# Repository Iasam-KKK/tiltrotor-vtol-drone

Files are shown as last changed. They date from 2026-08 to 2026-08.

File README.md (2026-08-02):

# Tri-Tiltrotor VTOL — PX4 + Gazebo Harmonic

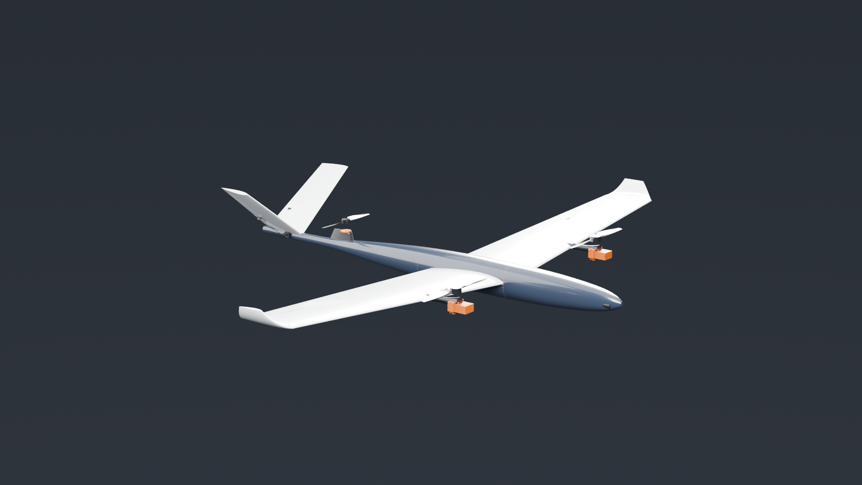
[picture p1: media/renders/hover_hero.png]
Tri-tiltrotor in the hover configuration, both wing rotors tilted thrust-up


A **three-rotor tilt-rotor VTOL** for PX4 SITL, built to the layout production
aircraft in this class actually use: two tilting rotors on the wing ahead of the
CG, and one **fixed, hover-only lift rotor** on a pylon at a waisted fuselage
station, ahead of a V-tail.

PX4 ships a **quad** tiltrotor (four motors, two of them tilting). This is a
**tri** — one fewer motor, ESC and propeller — and upstream provides no model
for it.

**Why the lift rotor is fixed, not tilting.** A tilting tail rotor keeps
producing thrust in cruise, but it also lays a wake over whatever sits behind
it. A hover-only rotor is stopped in cruise, so the V-tail behind it flies in
clean air in the only regime where tail effectiveness matters for stability.
The fuselage narrows **57%** ahead of the pylon so the rotor draws air already
squeezed clear of most of the boundary layer. The cost is a stopped disc in
cruise — about 1 N against a 3.3 N requirement — which is why the BOM specifies
a **folding** propeller, and why `check()` refuses a fixed rotor without one.

```bash
git clone <this repo> && cd 04-tiltrotor-vtol
bash sim/install_into_px4.sh ~/PX4-Autopilot   # symlink airframe + model
cd ~/PX4-Autopilot && make px4_sitl gz_tri_tiltrotor
# then at the pxh> prompt:
#   commander takeoff
#   commander transition
```

| Hover — rotors up | Cruise — rotors forward |
|---|---|
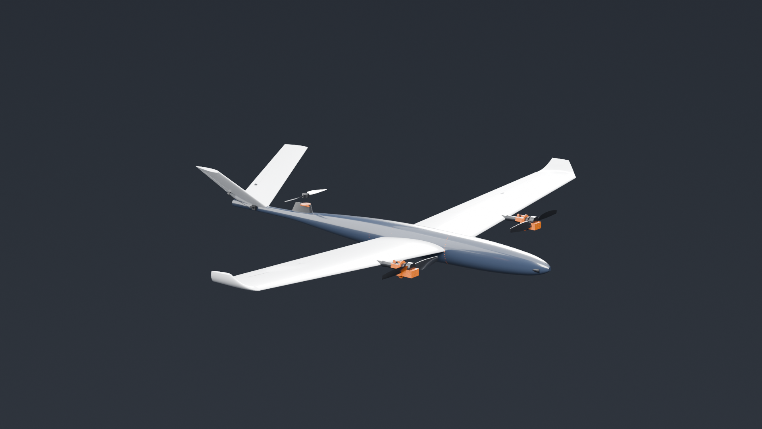
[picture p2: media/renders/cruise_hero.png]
cruise
| hover |  |

Both rendered from the **same CAD**, at the two ends of the tilt range. Nothing
was moved by hand: `render/assembly.json` is generated from `cad/params.py`, so
the pictures and the simulator are driven by one set of numbers. The camera is
generated too — it solves its own distance by projecting the aircraft's
bounding box onto the image plane, because a hardcoded camera position is a
latent bug in a parametric project: change the span and a wingtip leaves the
frame silently.

```bash
powershell -File render/render_all.ps1     # 12 renders, ~6 s each on GPU
```

---

## Verified, with numbers

Nothing below is asserted. Each row is produced by a script in `sim/` that you
can re-run.

| Claim | Measurement | How |
|---|---|---|
| Design closes | **118/118** invariants | `cad/params.py` |
| Model is valid | **13/13** | `sim/validate_model.sh` |
| CAD is manufacturable | STEP round-trip **0.000000 mm³** | `cad/gen_nacelle.py` |
| **It hovers** | climbed to **10.071 m** vs 10.0 m commanded | `sim/verify_hover.sh` |
| **It transitions** | both tilting nacelles **0.5° → 89.5°** | `sim/verify_transition.sh` |
| Control surfaces fit the wing | cutter **100.0%** inside the wing solid | `cad/probe_ctrl_fit.py` |
| Every avionics box fits its station | 7 items vs the lofted section | `cad/params.py` |
| ~~It glides~~ | **NOT VERIFIED — see below** | `sim/verify_glide.sh` |

The hover and transition rows were re-measured after the pitch and geometry
corrections: hover reached **10.068 m** against 10.0 m commanded (5/5), and
both tilting nacelles ran **0.0° → 89.6° / 89.5°** with 3/3 rotors turning.

### The glide test does not currently test anything

`sim/verify_glide.sh` was the only script here that tests the **aerodynamic**
model rather than a mechanism, and it is the one that does not work. It is
listed as unverified above rather than quietly dropped.

It commands the descent the polar predicts as an offboard **NED velocity**
setpoint, then measures travel over height lost. Run unattended end to end
(`sim/verify_glide_auto.sh`), the aircraft flies at **35.5 m/s** against a
commanded 14.76, sinking **0.164 m/s** against a predicted 0.941 — an implied
glide ratio of **217** for an airframe whose derived (L/D)max is ~15.

The cause is not the drag model. **PX4 does not act on offboard NED velocity
setpoints in fixed-wing mode**; the setpoint is accepted and ignored, and the
fixed-wing controller holds altitude at its own airspeed. The measurement was
never of a glide. Two things kept this hidden:

- The script's only sanity check was "did it descend at all". Powered
  near-level flight descends slightly, and dividing by a near-zero sink rate
  produces a magnificent glide ratio. There is now a **speed gate**: if ground
  speed exceeds 1.35 × the commanded best-glide speed, it reports powered
  flight instead of a number.
- The line that prints the comparison had a shell-quoting bug that crashed it
  (`g['v_best_glide_ms']` inside a single-quoted shell block ends the string).
  It had never once run, because every previous attempt exited earlier at the
  "not descending" branch. **A test that has never reached its assertion is
  not a passing test.**

The honest position: the drag polar is derived and traceable, and it is
**untested**. Testing it needs a throttle-cut path — commanding zero thrust
directly, or a fixed-wing descent PX4 will actually fly — not a velocity
setpoint.

Nacelle angle through the manoeuvre, read from Gazebo's joint state rather than
from a log line (0° = thrust up, 90° = thrust forward):

```
tilt_left    37.1   0.5   3.1   1.4   3.5   3.7  38.0  89.5  89.5  89.5
tilt_right   37.1   0.5   7.6   5.8   7.9   8.0  41.5  89.6  89.6  89.6
             spawn  ├──── hover ────┤ ├rotating┤ ├─── cruise ───┤
```

The fixed lift rotor is emitted as a `fixed` joint, so it correctly never
appears in this data — and all 3 rotors are confirmed spinning.

⚠️ These numbers were re-measured after the airframe changed.

---

## The aircraft

| | |
|---|---|
| MTOW / span / wing area | 4.64 kg · 2.00 m · 0.520 m² |
| Wing loading · aspect ratio | 8.92 kg/m² · 7.69 (**8.31 effective**, winglets) |
| Airfoil | NACA 2410, taper 0.65, 4° dihedral, −2° washout, winglets |
| Rotor stations from CG | wing **+0.173 m** (tilting), lift rotor **−0.700 m** (fixed) |
| Tail | V-tail at **−0.870 m**, 36.4° dihedral, 0.128 m² |
| Hover trim (solved) | wing 17.79 N each, lift rotor 9.92 N (**21.8%** of lift) |
| Fuselage | 1.55 m, fineness **12.7**, waisted 70% at the pylon |
| Stall → transition → cruise | 11.51 → 14.96 → 19.0 m/s  (measured section) |
| Cruise L/D · best L/D | **13.05** at 19 m/s · **15.04** at 14.46 m/s |
| Unpowered glide | **3.81°**, sink **0.960 m/s** |
| Servos · peak servo current | 4 surface + 2 tilt · **15 A** (needs its own BEC) |
| Payload | 1080p nose camera, 45 g, 78° HFOV, 15° down |

### Why the rotors straddle the CG

A layout with both tilt rotors *behind* the CG cannot be trimmed in hover: total
lift acts aft of the centre of mass and produces an unopposed nose-down moment
of W·L that no combination of thrust and tilt can cancel. Putting rotors on both
sides of the CG is what makes hover pitch controllable, and it is enforced as an
invariant (`rotors straddle the CG`) rather than left to inspection.

### Yaw is single-path, deliberately

The wing pair carries yaw by differential tilt (ArduPilot calls the equivalent
`Q_TILT_TYPE=2`), travelling 15° aft of vertical. The tail nacelle **cannot**
contribute yaw — a centreline force in the x–z plane produces no moment about z
— so it carries pitch instead (`CA_SV_TL2_CT=2`). Yaw authority is 4.96 rad/s²
from wing vectoring alone.

---

## One source of truth

Every dimension lives in [`cad/params.py`](cad/params.py) and nowhere else.
The Gazebo model, the PX4 airframe, the lofted geometry and the printed nacelle
are all *generated* from it, so they cannot drift apart.

```
cad/params.py ──┬─→ gen_sdf.py           → sim/models/tri_tiltrotor/model.sdf
                ├─→ gen_airframe.py      → sim/airframes/4030_gz_tri_tiltrotor
                ├─→ gen_geometry.py      → lofted wing / fuselage / tail /
                │                          control surfaces / booms / props
                ├─→ gen_nacelle.py       → printable cradle, yoke, fit coupon
                ├─→ gen_manifest.py      → render/assembly.json  (Blender)
                ├─→ gen_flight_params.py → sim/ros2/flight_params.json  (ROS 2)
                ├─→ gen_layout.py        → docs/equipment-bay.svg
                ├─→ gen_bom.py           → docs/BOM.csv
                ├─→ gen_cfd_surface.py   → cfd/geometry/  (wetted OML only)
                └─→ gen_cfd_case.py      → cfd/case/      (OpenFOAM)
```

`gen_flight_params.py` exists because the ROS 2 teleop node runs under WSL's
system Python and cannot import `params.py` (Windows-side 3.12 venv with
build123d). Without it the glide speed would have to be retyped into the node
and would drift the moment the polar changed.

## Running it

See [`RUN.md`](RUN.md) — three commands, plus the environment traps that make
the difference between "it works" and "it silently does nothing".

`params.check()` runs 118 invariants in arithmetic *before* any CAD kernel or
simulator starts, and refuses to emit an aircraft that cannot fly. It has
already caught, on real runs:

- a mass budget short by **0.88 kg** (battery folded into "fuselage")
- a horizontal tail sitting **inside the tail rotor's disc**, which would have
  flown in its own wash
- its own bad arithmetic — a bolt-pattern check that double-counted and failed
  a design that was fine

### Six defects this structure caught, and one it didn't

Every one of these passed the invariant suite as it stood. They are listed with
what was wrong, how it was actually found, and what now prevents a repeat —
because "we have 118 checks" is worth nothing next to what the checks missed.

| Defect | Found by | Why the checks missed it |
|---|---|---|
| **Aerofoil built upside down.** `Plane(x_dir=(1,0,0), z_dir=(0,1,0))` has in-plane Y = `(0,0,-1)`, so NACA 2410's camber pointed at the ground on the wing, winglets, tail and propeller blades. | Extruding one root section in isolation: sketch Y `-21.5..+10.2` → model z `-10.2..+21.5` | Nothing inspected the mesh. `LiftDrag` reads coefficients and joint angles, never geometry, so it flew correctly while looking wrong. A first probe read the wing **bounding box** and concluded the opposite — the winglet at +152 mm dominates it. |
| **Wing boom slung under the wing.** Centred 14 mm below the chord line, spanning −22.0…−6.0 mm against a skin at −8.3…+18.4 mm: 13.7 mm proud, applying nacelle load on a lever arm instead of in shear. | Measuring the section at the boom station | The boom's `z` was a literal in `gen_geometry.py` that `params.py` never saw. Now asserted **where the number lives**, not in `check()`. |
| **Control surfaces overlapping the wing.** Built as separate solids while the wing kept its full chord — two solids in one space. | Volume arithmetic: the wing lost 57.5 cm³ to a 478 cm³ cutter | No check compared the surfaces to the wing. Now the surface *is* the wing's own aft portion (`wing ∩ prism`), 100% by construction. |
| **V-tail bolted to nothing.** The body ended at −0.872 m; the tail root chord runs to −1.005 m. 133 mm of a 180 mm root cantilevered into open air. | Reading the station table against the tail chord | The invariant was called *"fuselage is long enough to carry the tail"* and compared **two lengths** (1.35 vs 0.956 m). It never asked where anything was. |
| **Takeoff nose-up.** `CA_ROTOR*_CT` defaults to 6.5 for every rotor; ours are 38 N and 25 N. PX4 asked the tail for 9.32 N and got ~66%, leaving ~2.2 N·m of unopposed nose-up at 0.700 m aft. | PX4's own `module.yaml`: *"Thrust = CT · u²"* | Stock `4020_gz_tiltrotor` omits `CT` too — correctly, because its four rotors are identical and the error is common-mode. Ours are not. |
| **CG 11.2 mm off.** `base_link`'s inertial sat at the origin while five links hung mass elsewhere; every `CA_ROTOR*_PX` is quoted from the CG. | Summing m·x across the emitted SDF | `params.check()` verified the *design* CG arithmetic. Nothing verified that the *generated SDF* put mass where the design said. |
| **BOM had no control-surface servos.** Listed 3 tilt servos, zero aileron or ruddervator servos, while PX4 has allocated four (`CA_SV_CS0..3`) since the V-tail was adopted. | Reading the BOM against the airframe | Nothing cross-checked the parts list against the control allocation. An aircraft built to that list would have had no roll, pitch or yaw in forward flight. |

The pattern worth taking away: **five of the seven were checks whose *name*
claimed a guarantee their *arithmetic* could not deliver.** A check with a
constant on both sides (`3 <= 4`) cannot fail, and cannot help.

### What AVL found, and what it fixed

`cad/gen_avl.py` emits a vortex-lattice model from the same `params.py`;
`aero/run_avl.sh` trims it at the cruise CL. It immediately found two defects,
both now fixed.

**1. The MAC was located as if the wing were rectangular.** The wing is placed
by its **root** quarter-chord, but the aircraft balances about the **mean
aerodynamic** chord — and on a wing with 3° of leading-edge sweep those are not
the same station. The MAC quarter-chord sits **24.4 mm aft** of the root's.
Every call site computed `CG_MAC_FRACTION * WING_CHORD - 0.25 * WING_CHORD`
inline, in **eight separate files**, and all eight placed the root where the MAC
belonged. The whole wing sat 24.4 mm too far aft.

The result: `params.py` printed *"CG at 28% MAC"* while the aircraft actually
had its CG at **18.6% MAC**. The error was invisible because it is in the safe
direction — more nose-heavy, more stable — and because the expression was
duplicated rather than written once.

The fix names the distinction that caused it: `mac_quarter_chord_x()` and
`wing_root_quarter_chord_x()` are now two functions in `params.py`, and nothing
computes either inline. Measured after the fix: **CG at 28.00% MAC.**

**2. The V-tail had no incidence, so the elevator carried the trim.** The
ruddervators sat 8.67° from neutral in cruise, permanently. `params.py` had no
tail incidence parameter at all. `aero/solve_tail_incidence.sh` runs AVL at two
incidences and interpolates to zero elevator — the relationship is linear, so
two runs give it exactly. Answer: **−2.49°**, leading edge down.

| trimmed at cruise CL 0.403 | before | after |
|---|---|---|
| **Static margin** | 28.3% MAC | **19.5%** |
| **Trim elevator** | **−8.67°** | **+0.015°** |
| Induced drag CDind | 0.0068252 | **0.0063360** (−7.2%) |
| Span efficiency (Trefftz) | 1.144 | **1.236** |
| Cm_α | −1.474 | −1.018 |
| Cn_β (yaw stiffness) | 0.0658 | 0.0644 — kept |
| Cmq (pitch damping) | −12.77 | −12.29 — kept |
| Spiral `Clb·Cnr/Clr·Cnb` | 1.065 | **1.127** |

Both axes of authority survived intact, which was the point of fixing the CG
rather than shrinking the tail.

### Why the tail was not resized

The obvious response to 28% static margin is a smaller tail. AVL says no.
Sweeping tail area (`aero/sweep_tail.sh`):

| tail area | SM % | Cmq | Cn_β |
|---|---|---|---|
| 1.00 | 28.3 | −12.77 | 0.0658 |
| 0.70 | 22.1 | −9.11 | 0.0458 |
| 0.50 | 17.9 | −6.73 | 0.0324 |

**Halving the tail buys 10 points of static margin and costs 47% of the pitch
damping and 51% of the yaw stiffness** — and 0.0324 is below the ~0.05 usually
wanted for directional stability. Cmq scales with area × arm², so it falls
faster than the static margin improves; a tail *volume coefficient* cannot see
that, which is exactly the trap the sizing literature warns about.

It also fights itself: removing ~66 g of tail structure 0.870 m aft moves the
CG **12.6 mm forward**, giving back nearly half the margin just bought. And a
V-tail carries pitch and yaw on the *same* surfaces, so shrinking costs both at
once — there is no trade available.

Fixing the CG achieved more, for free.

### Aerodynamics are measured, not guessed

The section coefficients were hand-estimated, then derived from thin-airfoil
theory, and are now **measured** — XFOIL run on NACA 2410 at this aircraft's own
Reynolds numbers (`aero/run_xfoil.sh`, Ncrit 5, because the wing is printed).

| 2-D section | Guessed | Theory | **XFOIL, measured** |
|---|---|---|---|
| CL_α | 5.20 /rad | 6.283 (2π) | **6.022** |
| CL_max | 1.20 | 1.40 | **1.219** |
| CD_min | 0.028 | 0.0069 | **0.00868** |
| Stall α | 15° asserted | 15.5° | **13.18°** |

The measurement is taken at the **converged stall Reynolds number of 199,489**,
which is a fixed point: CL_max sets the stall speed, the stall speed sets the
chord Reynolds number, and that sets CL_max.

**Theory was wrong in the direction that flatters the aircraft, and worst where
it matters.** CL_max was 15% optimistic at exactly the low Reynolds number where
stall happens, and CD_min of 0.0069 turned out to be roughly the *Re 1,000,000*
figure for a wing that never exceeds 393,000. What that cost:

| | before | after |
|---|---|---|
| Stall speed | 10.74 m/s | **11.51 m/s** (+7.2%) |
| Transition speed | 13.96 | 14.96 m/s |
| CD0 (whole aircraft) | 0.02132 | 0.02310 |
| (L/D)max | 15.65 | **15.04** (−3.9%) |

All **118 invariants still pass** — the aircraft still closes, the envelope just
sits 7% higher. One consequence is now decisive rather than marginal: the
minimum-power speed (max endurance for a propeller aircraft) works out at
**0.955 × stall**, i.e. below stall. It is not a speed this aircraft can fly.
Loiter at 1.2 × stall = **13.81 m/s**.

---

## Against what PX4 ships

| | stock `gz_tiltrotor` | this |
|---|---|---|
| Configuration | quad, 2 of 4 tilt | **tri**, 2 tilting + 1 fixed lift |
| Motors / ESCs / props | 4 | **3** |
| Fuselage | one box, 0.55 × 2.144 × 0.05 m | lofted through 15 stations, **waisted** at the pylon |
| Main wing lift surface | **none** — elevons stand in for the wing | per-panel, at computed centres of pressure |
| Wing | rectangular plank | NACA 2410, tapered, dihedral, washout, **winglets** |
| Tail | separate stabiliser + fin | **V-tail**, dihedral derived from required effectiveness |
| Rudder | ±0.01 rad, LiftDrag **commented out** | functional, both ruddervators live |
| Airspeed sensor | absent | present (required to gate transition) |
| Aero coefficients | hand-entered | **derived from the section** |
| Verification | none | 4 scripts, 74 assertions |

---

## Repository layout

```
cad/     params.py + four generators, STEP output
sim/     model, airframe, worlds, and the verification scripts
media/   video masters (generated; see sim/capture_video.sh)
docs/    build notes and the environment gotchas
```

### Scripts

| Script | Does |
|---|---|
| `sim/install_into_px4.sh` | symlinks airframe + model into a PX4 checkout, idempotent |
| `sim/validate_model.sh` | SDFormat validity, structure, headless load |
| `sim/verify_hover.sh` | commands takeoff, measures altitude from Gazebo's pose topic |
| `sim/verify_transition.sh` | reads actual tilt joint angles through the manoeuvre |
| `sim/verify_glide_auto.sh` | PX4 + agent + scripted flight + glide measurement, unattended |
| `sim/capture_video.sh` | headless flight recording, Gazebo → ROS 2 → MP4 |
| `sim/run_gui.sh` | interactive run with the Gazebo GUI |

---

## Pinned versions

Reproducibility is the point; these are the versions it was verified against.

| | |
|---|---|
| PX4-Autopilot | **v1.17.0** |
| Gazebo | **Harmonic, gz-sim 8.11.0** |
| ROS 2 | **Jazzy** (used for the video bridge) |
| Ubuntu | **24.04 noble** (WSL2) |
| build123d | **0.11.1** on Python 3.12 |
| Airframe ID | **4030** `gz_tri_tiltrotor` |

---

## Honest limitations

- **Simulation only.** No physical aircraft exists. Nothing here has been flown
  or wind-tunnel tested, and the nacelle tolerances are verified in CAD only.
- **Aerodynamic coefficients are derived from thin-airfoil theory and published
  section data**, not from CFD or measurement. They are traceable, not exact.
- **Inertia is estimated** from a rod-and-point-mass model, good to perhaps
  ±25%. The control-authority margins are wide enough that this does not change
  any conclusion, but it is an estimate.
- **The transition is verified as "the nacelles rotate through 90° in flight".**
- **The drag polar is untested.** See the glide section above. It is derived
  from the section and the planform and nothing has yet measured it.
- **No endurance figure exists.** Battery mass is an input to `params.py`, not
  a result: there is no power-required calculation and no flight-time estimate,
  so the aircraft cannot currently answer the first question any buyer asks.
- **No constraint analysis.** Wing loading (8.92 kg/m², 1.83 lb/ft²) and
  installed thrust were chosen, not derived from intersecting hover, climb,
  transition and cruise constraints.
- **Stability is now computed, and it found two things** — see below.

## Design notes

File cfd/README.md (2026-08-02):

# CFD — measuring the drag polar

`params.py` **derives** a drag polar from thin-airfoil theory and the planform.
Nothing has ever **measured** it. `sim/verify_glide.sh`, which was supposed to,
does not work (see the project README). This directory is the attempt to close
that gap.

```bash
bash cfd/install_openfoam.sh          # once; then open a NEW shell
.venv-cad/Scripts/python.exe cad/gen_cfd_surface.py
.venv-cad/Scripts/python.exe cad/gen_cfd_case.py --alpha 0
bash cfd/run_case.sh                  # ~30-90 min
bash cfd/sweep_alpha.sh 0 2 4 6 8     # overnight; produces polar.csv
```

Everything under `case/` and `geometry/` is **generated** and git-ignored. The
two generators in `cad/` are the source, so the CFD geometry cannot drift away
from the flying model or the printed parts.

## Read this before believing a number

**The Reynolds number is the problem.** 329,000 at cruise, 223,000 at loiter,
186,000 at stall, all on the MAC. That is low-Re transitional flow. The real
boundary layer runs laminar over a meaningful fraction of the chord and often
separates into a bubble before reattaching turbulent.

A fully-turbulent k-ω SST run assumes turbulence from the leading edge and will
**overpredict skin-friction drag**, sometimes by tens of percent at this scale.
The case therefore defaults to **k-kL-ω**, which is transition-sensitive. That
is an improvement, not a solution: transition models at Re 2×10⁵ are themselves
sensitive to the inlet turbulence intensity, which here is a guess (0.1%).

So: **CFD is a bracket, not an oracle.** Thin-airfoil theory underpredicts CD0;
fully-turbulent RANS overpredicts it. Expect the truth between them, and say so
in any listing rather than quoting a CFD number as measurement.

**Cheaper tools answer most of this faster.** XFOIL gives 2-D section polars at
the exact Reynolds number in seconds, and AVL gives span loading, induced drag
and the stability derivatives this project still lacks, in minutes. Run those
first. CFD earns its cost on things they cannot do: fuselage interference, the
waisted pylon, nacelle drag, and prop-wing interaction.

## What the case is

| | |
|---|---|
| Solver | `simpleFoam`, steady incompressible RANS |
| Turbulence | `kkLOmega` (default) or `kOmegaSST` |
| Geometry | unpowered airframe — **props excluded on purpose** |
| Domain | 5 spans out, 10 spans downstream, `slip` farfield |
| Reference | Aref 0.52 m², lRef 0.26 m, CofR at the CG (the origin) |

**Props are excluded deliberately.** The polar being tested is the unpowered
one. A stationary disc in the mesh adds drag the polar never claimed.

**Internal parts are excluded**, measured rather than assumed: `booms`,
`structure`, `linkages` and `formers` all sit inside the wing or fuselage
envelope. See the table in `cad/gen_cfd_surface.py`.

## Things that will bite

- **`locationInMesh` must be outside every solid.** It is at `(3, 2, 2)`, ahead
  of and above the nose. A point inside the fuselage meshes the *interior* and
  produces a beautiful, meaningless result.
- **Meshing is not idempotent.** `run_case.sh` deletes `constant/polyMesh` and
  `processor*` first; without that you silently solve the previous alpha's mesh.
- **Changing alpha means regenerating the case**, not editing `U`. The angle
  also sets `liftDir` and `dragDir`; edit only the inlet and your CL and CD are
  resolved onto the wrong axes.
- **WSL memory.** It defaults to half the host — 15 GB of your 32 GB. snappy
  wants roughly 1 GB per million cells. Set `memory=24GB` in `%USERPROFILE%\.wslconfig`
  and `wsl --shutdown` before meshing.
- **Check y+ after the first run.** The case uses low-Re wall treatment with 8
  layers; if y+ is well above 1 the layers did not resolve and the drag is
  wrong. `simpleFoam -postProcess -func yPlus -latestTime`.
- **One alpha is not a polar.** CD0 and the induced factor only separate when
  you fit CD against CL² across several angles. That is what `sweep_alpha.sh`
  does, and its intercept is the number to compare.

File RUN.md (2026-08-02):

# RUN — tri-tiltrotor simulation

Three commands, three terminals. Copy-paste, no thinking required.

---

## 0. Connect to the desktop first

⚠ **The Gazebo GUI must be launched from the xrdp session, not from a plain
`wsl.exe` window.** Under WSLg the window opens and composites solid black —
measured, every render-engine and Qt-backend combination, `mean=0.00`. A
WSLg-launched shell has `DISPLAY=:0` and puts you straight back there.

1. Windows **Remote Desktop** (`mstsc`) → `localhost:3390`
2. Session type **Xorg**, your WSL username + password
3. Open a terminal **inside that desktop**

Sanity check before anything else — want `D3D12`, not `llvmpipe`:

```bash
glxinfo -B | grep -i 'OpenGL renderer'
```

---

## The three commands

### 1. PX4 + Gazebo  — run this one INSIDE the RDP desktop

```bash
bash /mnt/e/ME/UAV/projects/04-tiltrotor-vtol/sim/run_gui.sh
```

Wait for `INFO [commander] Ready for takeoff!` and the `pxh>` prompt.
Takes ~40 s (build check + Gazebo spawn).

### 2. uXRCE-DDS agent — any terminal, no X needed

```bash
bash /mnt/e/ME/UAV/projects/04-tiltrotor-vtol/sim/ros2/run_agent.sh
```

Without this there are **no** `/fmu/*` topics and nothing errors — `ros2 topic
list` just comes back short. Leave it running.

### 3. Keyboard teleop — any terminal

```bash
bash /mnt/e/ME/UAV/projects/04-tiltrotor-vtol/sim/ros2/teleop.sh
```

Wait for `position acquired: x=… y=…`. If it says
`waiting for PX4 position data` for more than 8 s it will tell you what to check.

```
space   arm            -> wait for  [PX4] now ARMED
o       offboard       -> wait for  [PX4] nav_state -> 14 (OFFBOARD)
w / s   climb / descend
a / d   YAW left/right     <- the vectored-yaw demo: the nacelles split apart
i / k   forward / back
j / l   slide left / right
t / b   transition to forward flight / back to hover
g       GLIDE — unpowered descent at best L/D
p       leave glide, back to powered flight
q       quit (disarms first)
```

### Glide test

```bash
# in teleop:  space -> o -> w (climb) -> t (forward flight) -> g (glide)
bash /mnt/e/ME/UAV/projects/04-tiltrotor-vtol/sim/verify_glide.sh
```

Measures horizontal travel ÷ altitude lost from Gazebo's pose topic and
compares it against the L/D the drag polar predicts (**15.65 at 15.01 m/s**,
sink **0.957 m/s**). That number is derived in `params.py` from the NACA
section and the planform, so this is a test of the aerodynamic model, not a
demonstration of a descent.

---

## Worth having open too

Camera follows the aircraft instead of watching it fly away:

```bash
bash /mnt/e/ME/UAV/projects/04-tiltrotor-vtol/sim/follow_drone.sh
# OFFSET="0 -6 2"  ... side-on, best for watching the nacelles tilt
# OFFSET="0 0 12"  ... top-down, best for seeing yaw
# --stop           ... release the camera
```

Live nacelle angles — this is how you *see* yaw happen:

```bash
bash /mnt/e/ME/UAV/projects/04-tiltrotor-vtol/sim/watch_tilt.sh
```

---

## When something is wrong

One command, tells you what is actually true rather than what should be:

```bash
bash /mnt/e/ME/UAV/projects/04-tiltrotor-vtol/sim/status.sh
```

It reports process state, whether the GUI window is really mapped, and — the
one that matters — the **publisher count** on `/fmu/out/vehicle_status`. A topic
appearing in `ros2 topic list` proves nothing: the teleop node's own
subscriptions create those names with no agent connected at all.

| Symptom | Cause |
|---|---|
| GUI black | launched from WSLg, not the RDP session |
| No `/fmu` data | agent not running, or started before PX4 (restart it *after*) |
| Teleop stuck "waiting for position" | same as above |
| Nothing moves | not armed — `space` first, watch for `[PX4] now ARMED` |
| GUI died, sim still running | `bash sim/run_gui_client.sh -b` reattaches without killing the flight |

---

## Rebuilding the model after a CAD change

`params.py` is the only place any dimension lives; everything else is generated.

```bash
cd /mnt/e/ME/UAV/projects/04-tiltrotor-vtol/cad
/mnt/e/ME/UAV/.venv-cad/Scripts/python.exe gen_geometry.py   # meshes
/mnt/e/ME/UAV/.venv-cad/Scripts/python.exe gen_sdf.py        # Gazebo model
/mnt/e/ME/UAV/.venv-cad/Scripts/python.exe gen_airframe.py   # PX4 airframe
/mnt/e/ME/UAV/.venv-cad/Scripts/python.exe gen_manifest.py   # Blender manifest
```

The model is symlinked into PX4, so regenerating takes effect on the next run
with no reinstall. If the airframe file changed, PX4 needs a rebuild — that is
what `run_gui.sh` does for you.

---

## Looking at the CAD, and exporting STL

Both run from Windows PowerShell, not WSL — FreeCAD is a Windows install here.

```powershell
cd E:\ME\UAV\projects\04-tiltrotor-vtol
powershell -File tools\open_in_freecad.ps1   # GUI, coloured by role, annotated
powershell -File tools\export_stl.ps1        # headless -> cad\out\stl\
```

Both regenerate the STEP assembly from `params.py` first, so what you see and
what you export are what the parameters currently say.

STL output lands in `cad/out/stl/`:

| folder | frame | for |
|---|---|---|
| `assembly/` | flight positions | load all 19 together, get an assembled aircraft |
| `print/` | each part on the origin, z=0 | dropping straight into a slicer |
| `tri_tiltrotor_full.stl` | flight positions, one mesh | previews, marketplace, anything single-file |

⚠ **Units.** These STLs are in **millimetres**. The meshes in
`sim/models/tri_tiltrotor/meshes/` are in **metres** because Gazebo wants them
that way — a slicer reads that wing as 2.1 mm long. Don't cross the streams.

⚠ **13 of the 19 parts are over a 256 mm bed** (wing 2126 mm, structure
1841 mm, fuselage 1550 mm). They export correctly and are watertight, but they
are aircraft-scale assemblies, not print-ready parts — they need splitting with
joints before anyone slices them. The six that fit as-is are the nacelle yokes
and cradles, the tail motor mount, and `prop_tail`.

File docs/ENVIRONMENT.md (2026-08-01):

# Environment notes and traps

Everything here was found the hard way while getting this project to run on
**Windows 11 + WSL2 + Ubuntu 24.04 + ROS 2 Jazzy + Gazebo Harmonic**. Each
entry cost real time; none of it is obvious from the upstream docs.

---

## PX4

### The source zip is missing 29 submodules

A GitHub source archive (`/archive/refs/tags/v1.17.0.zip`) contains **none** of
PX4's 29 submodules, and the build fails one at a time, each attempt getting
further than the last. SITL needs only ten of them:

```
src/modules/mavlink/mavlink              src/lib/heatshrink/heatshrink
src/lib/events/libevents                 src/lib/crypto/monocypher
src/modules/uxrce_dds_client/Micro-XRCE-DDS-Client
src/lib/cdrstream/cyclonedds             src/lib/crypto/libtomcrypt
src/lib/cdrstream/rosidl                 src/lib/crypto/libtommath
src/drivers/gps/devices
```

The other 19 are NuttX, other simulators, and board-specific drivers — over a
gigabyte that SITL never touches.

### Submodules must be pinned, or the build fails confusingly

Cloning them at `HEAD` produces a **compile error, not a checkout error**:

```
src/drivers/gps/gps.cpp:541: error: 'class GPSHelper' has no member named 'shouldInjectRTCM'
```

That is version skew: v1.17.0's source against a newer PX4-GPSDrivers. Eight of
our ten were at the wrong commit. The pinned SHAs are recoverable from the
GitHub contents API even though the zip dropped them:

```
GET /repos/PX4/PX4-Autopilot/contents/<submodule-path>?ref=v1.17.0   -> .sha
```

Then `git fetch --depth 1 origin <sha> && git checkout FETCH_HEAD`.

### The Makefile refuses to build without `.git`

```
Makefile:39: *** YOU HAVE TO USE GIT TO DOWNLOAD THIS REPOSITORY. ABORTING.
```

It only tests `$(wildcard .git)`, so `git init` satisfies it — but the build
later uses `git describe` for version strings, so tag it too:

```bash
git init -q && git add -A && git commit -qm "snapshot" && git tag v1.17.0
```

### Run SITL from the build directory

`rcS` and the baked ROMFS resolve relative to the working directory:

```bash
cd build/px4_sitl_default && ./bin/px4 etc/init.d-posix/rcS
```

Running `./build/px4_sitl_default/bin/px4 -s etc/init.d-posix/rcS` from the
source root gives `Error opening startup file`.

### `commander mode takeoff` is not a command

```
ERROR [commander] argument takeoff unsupported.
```

It is `commander takeoff`, and it arms as part of its own sequence. Arming
separately first gets you `Disarmed by auto preflight disarming`.

---

## Control allocation

### Tilt angle zero means UP

From `src/modules/control_allocator/module.yaml`, `CA_SV_TL{i}_MINA`:

> *"Defines the tilt angle when the servo is at the minimum. An angle of zero
> means upwards."*

So **0° = hover, +90° = towards the `CA_SV_TL{i}_TD` azimuth = cruise**, range
−90…+90. Vectored yaw therefore needs travel *past vertical in the negative
direction*, not past +90. Getting this backwards produces a model that looks
entirely plausible and cannot yaw.

### Servo order is control surfaces first, then tilts

PX4 allocates `CA_SV_CS0..n` before `CA_SV_TL0..n`. Stock `4020_gz_tiltrotor`
demonstrates it: 3 surfaces on `SIM_GZ_SV_FUNC1-3`, then the tilt-angle
parameters land on servos 4 and 5. Put tilts first in the SDF and tilt commands
silently drive your ailerons.

`gz` topic `servo_N` corresponds to PX4 `SIM_GZ_SV_*{N+1}` — gz is 0-indexed,
PX4 is 1-indexed.

### Up to four tilt servos are supported natively

`__max_num_tilts: 4`. A tri-tiltrotor needs no custom allocator.

---

## Gazebo

### The airspeed sensor name is hard-coded

`GZBridge.cpp:281` subscribes to exactly:

```
/world/<world>/model/<model>/link/airspeed_link/sensor/air_speed/air_speed
```

The link **must** be `airspeed_link` and the sensor **must** be `air_speed`.
An identical sensor on `base_link` under any other name publishes correctly and
is never read. The symptom is not an error:

```
INFO  [airspeed_selector] No airspeed sensor detected. Switch to non-airspeed mode.
WARN  [health_and_arming_checks] Preflight Fail: Airspeed invalid
```

which reads like a sensor fault rather than a naming one.

### Rotor spin axes must NOT be `expressed_in="__model__"`

The tilt joint axes may be. The **rotor** axes must be in the joint frame so
they rotate with the nacelle. Pin them to the model frame and thrust points up
forever regardless of tilt — the aircraft hovers perfectly and never
transitions, which presents as a controller bug.

### `use_parent_model_frame` is legacy SDF 1.4

Stock PX4 models still use it. The modern spelling is the attribute
`<xyz expressed_in="__model__">`.

### XML comments cannot contain `--`

A generated banner reading `GENERATED FILE -- DO NOT EDIT` makes the whole
document unparseable.

### `<save enabled="true">` on a camera does not work here

It writes no files and the run dumps core. Take frames off the image **topic**
instead — see `sim/record_video.py`.

### `joint_state` carries a pose AND an angle

Each joint block has `pose { position { x y z } }` (a **translation**) and,
for revolute joints, `axis1 { position: }` (the **angle**, radians). Scraping
`position:` naively yields nonsense — an early version of
`verify_transition.sh` reported −103 231° of nacelle tilt and still printed
PASS.

---

## WSLg

### `GALLIUM_DRIVER=d3d12` must be set in every script

Ubuntu's `~/.bashrc` returns early for non-interactive shells, and
non-interactive bash does not source it at all. **Any** script run via
`wsl -- bash foo.sh` therefore sees no `GALLIUM_DRIVER` and silently falls back
to llvmpipe software rendering, on a machine whose interactive shells are fully
GPU accelerated.

### ogre2 cannot create a GL context

```
glx: failed to create drisw screen
[GUI] [Err] [Application.cc:912] [QT] Failed to create OpenGL context
```

`--render-engine ogre` (v1) works. PX4 passes this through with
`PX4_GZ_SIM_RENDER_ENGINE=ogre`, which reaches both the server and the GUI.
This is **not** a GPU capability problem — `glxinfo` reports OpenGL 4.6 core on
D3D12 (RTX 5070), accelerated.

### Mesh visuals DO work — the crash was elsewhere

An earlier reading of this said mesh rendering was broken. It is not. Mesh
visuals render fine in the capture pipeline. The segfault was specific to
loading `test.sdf` with the Sensors system present, and the stock PX4 x500
crashed the same way, so it was never our geometry.

The validation world now omits `gz-sim-sensors-system` entirely — it exists to
check structure and physics, neither of which needs a renderer — and the
capture world keeps it. Separate concerns, separate worlds.

### The Gazebo GUI window does not render

The process is healthy, the world connects, no errors are logged, and the X
window is created — at **1×1 pixels**, or later composited as a solid black
rectangle titled `[WARN:COPY MODE]`. Clearing `~/.gz/**/gui.config` does not
help. Neither does `QT_QPA_PLATFORM=xcb`.

**Do not fight this.** Render headless and record from the image topics
(`sim/capture_video.sh`). It is more reliable, it produces the video the
deliverables need anyway, and it removes the compositor from the critical path.

### Shell quoting across PowerShell → WSL → bash

Both wrappers interpolate before bash sees the string:

- **PowerShell** expands `$VAR` inside double quotes and treats `|` as a pipe.
- **Git Bash** expands `$PATH` — whose Windows value contains
  `Program Files (x86)`, and the parentheses break the inner bash parse.
- Git Bash also rewrites `/mnt/...` via MSYS path conversion, producing
  `C:/Program Files/Git/mnt/...`.

**Write a script file and run `wsl -- bash /path/script.sh`.** Inline commands
with variables, pipes or absolute paths will bite you.

### `/tmp` is tmpfs

A WSL restart deletes it. Logs you intend to read afterwards belong somewhere
persistent — this project uses `~/tritilt_logs`.

---

## Build tooling

Ubuntu 24.04 minimal ships **no pip and no ensurepip**. Bootstrap without sudo:

```bash
wget -c https://bootstrap.pypa.io/get-pip.py
python3 get-pip.py --user --break-system-packages
python3 -m pip install --user --break-system-packages kconfiglib jsonschema ninja
```

`~/.local/bin` is not on `PATH` for non-interactive shells; export it.

**Gazebo does not need a separate install.** ROS 2 Jazzy's vendor packages
provide the whole of Harmonic, including the `gz` CLI at
`/opt/ros/jazzy/opt/gz_tools_vendor/bin/gz`, and PX4 links against them
happily. Installing standalone `gz-harmonic` alongside would risk the verified
ROS stack for no gain.

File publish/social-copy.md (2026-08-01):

# Social copy — tri-tiltrotor VTOL

Written to the 8-slide carousel structure in the launch plan §7. Every number
below is measured, not estimated; if a claim cannot be traced to a script in
`sim/`, it is not here.

---

## LinkedIn carousel (8 slides, native PDF)

**1 — The finished thing**
> A VTOL that takes off like a helicopter and flies like a plane.
> Three rotors, not four. Built and verified in PX4 + Gazebo.
> Files are free.

**2 — The constraint**
> PX4 ships a **quad** tiltrotor: four motors, two of them tilting.
> That is four ESCs, four props and four mounts to buy, print and fail.
> I wanted the same job done with three.

**3 — The problem nobody mentions**
> My first sketch put both tilt rotors at the back.
> It cannot hover. Total lift acts behind the centre of mass and there is
> nothing to oppose the nose-down moment.
> The rotors have to **straddle** the CG. That is the whole design.

**4 — CAD, with the maths visible**
> Every dimension lives in one file: `params.py`.
> It runs **50 invariants in arithmetic before any CAD kernel starts** and
> refuses to build an aircraft that cannot fly.
> It caught a mass budget short by 0.88 kg, and a horizontal tail sitting
> inside the tail rotor's own wash.

**5 — The simulation**
> PX4 v1.17.0, Gazebo Harmonic, custom airframe 4030.
> Hover: commanded 10 m, **climbed to 10.07 m**.
> Read from Gazebo's pose topic, not from a log line.

**6 — IT TRANSITIONS**
> The wing nacelles rotate **0° → 90°** in flight, read straight off the
> Gazebo joint angles rather than from a log line.
> The third rotor never tilts: it is a fixed lift rotor on a pylon, stopped
> in cruise with a folding prop, sitting at a fuselage waist that narrows
> **57%** so it breathes clean air.
> That is the layout production VTOLs use, and it is why.

**7 — What went wrong**
> The aerofoil was on **backwards** — blunt trailing edge into the airflow.
> It lofted fine, flew fine in sim (the aero model reads coefficients, not
> geometry) and looked almost right in a render.
> Found it by looking at a frame. One sign flip.

**8 — Free**
> Full repo: CAD, URDF, Gazebo world, PX4 airframe, 4 verification scripts.
> One command to run it.
> `github.com/<user>/tri-tiltrotor-vtol`

---

## Shorts / Reels (vertical, 30–45 s)

Cut from `media/master_vertical.mp4` — the nacelle camera.

- **0:00–0:03** hold on the aircraft, rotors vertical, sitting still
- **0:03–0:08** takeoff, straight up. Caption: *"Helicopter mode."*
- **0:08–0:16** the nacelle rotates. Caption: *"Watch the motor."*
- **0:16–0:25** level cruise, rotors forward. Caption: *"Plane mode."*
- **0:25–0:30** end card: *"All 3 rotors tilt. PX4 only ships 2 of 4. Free."*

The single most valuable second of footage is the nacelle mid-rotation. Do not
cut away from it.

---

## X / Twitter

> PX4's stock tiltrotor tilts 2 of its 4 rotors.
>
> I built one where all 3 tilt — including the tail rotor, which becomes a
> pusher in cruise.
>
> Hover: 10.07 m against 10 m commanded.
> Transition: all three nacelles 0° → 89.6°.
>
> Repo, airframe and verification scripts are free. 🧵

---

## MakerWorld / printable listing

**Title:** Tilt nacelle module for tri-rotor VTOL — 3× identical, PX4 airframe included

**Body:**
> The tilting motor nacelle from a tri-tiltrotor VTOL. Three identical modules
> make the whole aircraft: two on the wing, one at the tail.
>
> Cradle holds a 28xx motor on a 19 mm M3 pattern. Yoke clamps a 16 mm carbon
> boom and carries 686ZZ bearings on a 6 mm shaft. Servo sizing was computed
> against the actual tilt load — 20 kg·cm gives 7.9× margin.
>
> **Print the fit coupon first.** It is a few grams and verifies the bolt
> pattern and bearing seat before you commit filament to the real part.
>
> Clearance fits throughout, no press fits: +0.30 mm on shaft bores, +0.15 mm
> on bearing seats.
>
> ⚠️ **Tolerances verified in CAD only.** I do not own this aircraft — it is
> verified in simulation (PX4 v1.17.0 + Gazebo Harmonic), and the full ROS 2 /
> PX4 package is linked. The sim is the evidence, not a photo.

---

## Honesty rules for all of the above

- Never write "tested" or "flown" — it is **simulated**, and saying so is the
  differentiator, not the weakness.
- Every number quoted must come from a script in `sim/` that a reader can run.
- Lead with the failure in slide 7. The aerofoil-backwards story is more
  credible than any success slide, and it is true.

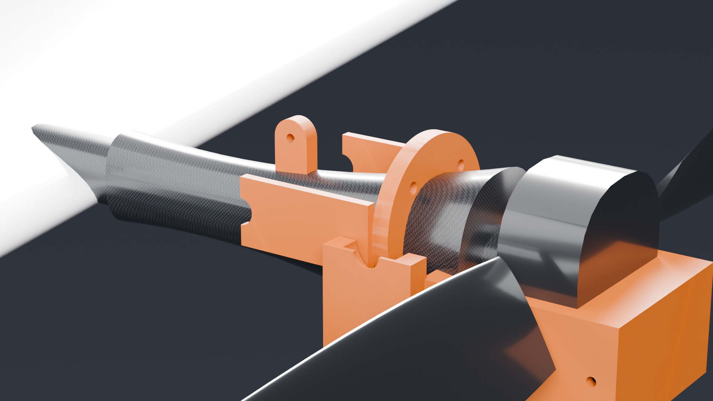
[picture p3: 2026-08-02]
media/renders/cruise_detail.png

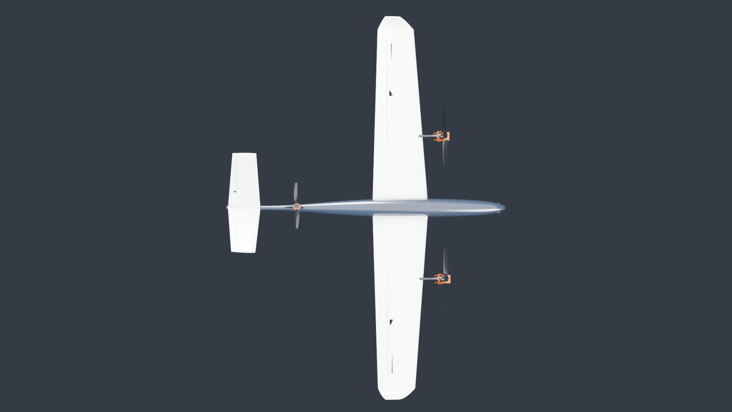
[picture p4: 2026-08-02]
media/renders/transition_top.png

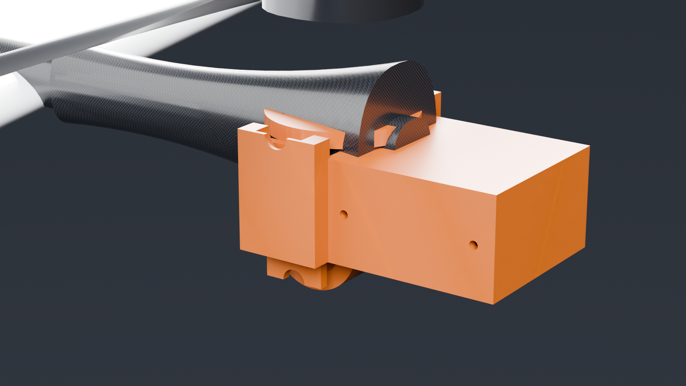
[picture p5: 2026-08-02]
media/renders/hover_detail.png

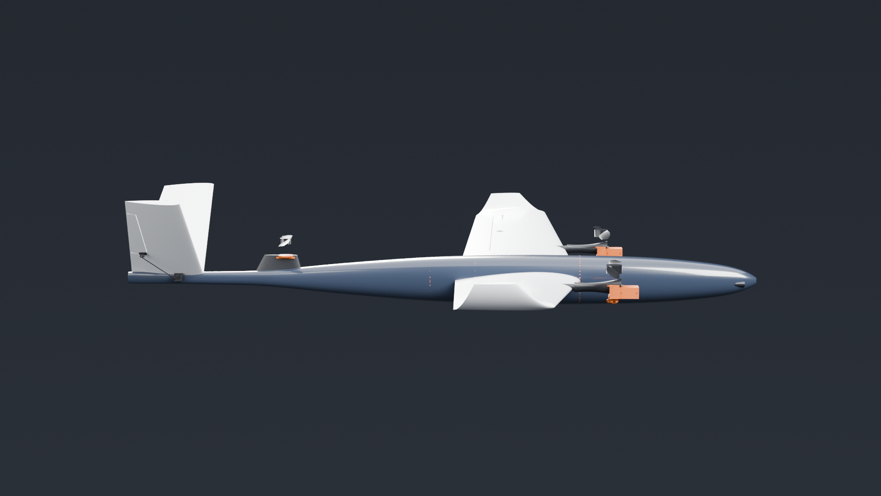
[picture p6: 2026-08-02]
media/renders/hover_front.png

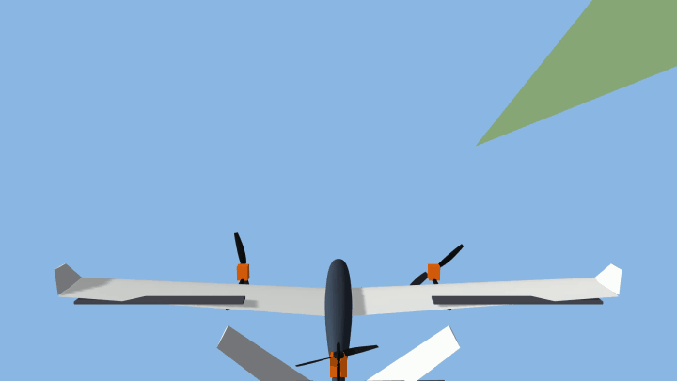
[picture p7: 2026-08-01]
media/hero.gif

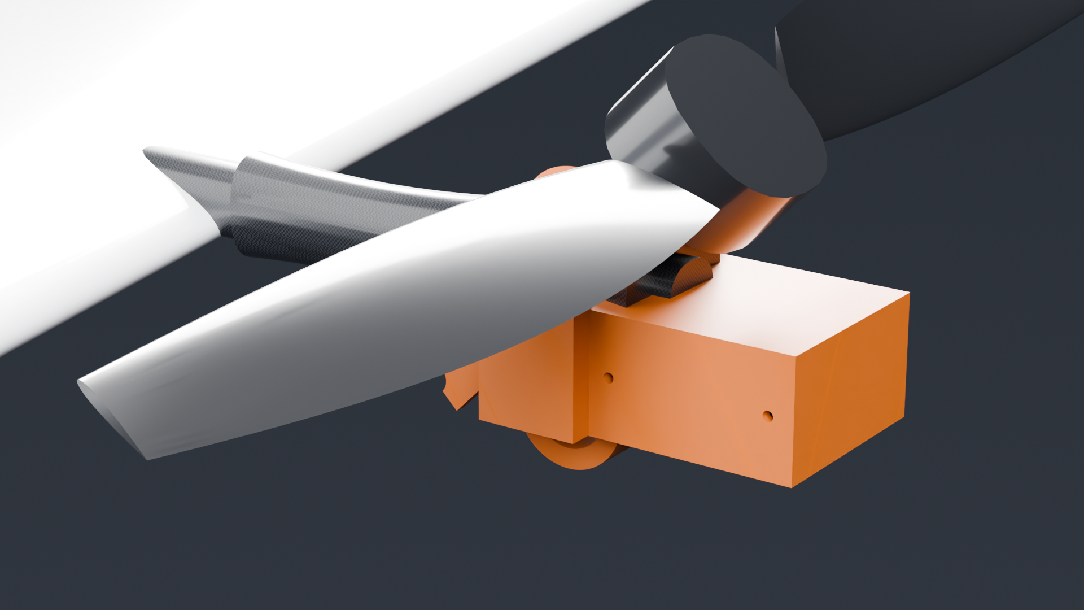
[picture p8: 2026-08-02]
media/renders/transition_detail.png

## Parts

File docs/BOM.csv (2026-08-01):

part | spec | qty | supplier | unit_usd | ext_usd | note
Brushless motor, wing nacelle | 28xx class, >= 38 N static thrust (3.87 kgf) | 2 | T-Motor / SunnySky / generic | 28.0 | 56.0 | hover draw 17.8 N each
Brushless motor, tail nacelle | 22xx class, >= 25 N static thrust | 1 | T-Motor / SunnySky / generic | 19.0 | 19.0 | hover draw 9.9 N
Propeller, wing | 13 in (330 mm), CW and CCW pair | 2 | APC / T-Motor | 6.5 | 13.0 | counter-rotating pair, torque cancels
Propeller, tail | 10 in (254 mm) | 1 | APC / T-Motor | 5.0 | 5.0 | reaction torque uncompensated; trimmed by wing vectoring
ESC | 30 A BLHeli_32 / AM32 | 3 | generic | 14.0 | 42.0
Tilt servo | digital metal-gear, >= 20 kg.cm | 2 | Savox / MKS / generic | 22.0 | 44.0 | 8.0x margin over computed tilt load; wing nacelles only
Bearing, tilt axis | 686ZZ, 6 x 13 x 5 mm | 6 | generic | 1.2 | 7.2 | two per nacelle; clearance fit, not press
Tilt shaft | 6 mm stainless, 60 mm long | 2 | generic | 1.5 | 3.0
Control surface servo | digital metal-gear, >= 8 kg.cm, 9 g class | 4 | Savox / MKS / generic | 13.0 | 52.0 | 2 aileron + 2 ruddervator; mounts in the wing/tail bays
Servo pushrod + clevis | M2 threaded rod, ball link | 6 | generic | 1.8 | 10.8 | one per servo
BEC, servo rail | 6S in, 5-6 V out, >= 10 A continuous | 1 | Mateksys / generic | 18.0 | 18.0 | 6 servos x 2.5 A stall = 15 A peak; the FC regulator gives 1.5 A
Carbon boom | 16 mm OD tube, 400 mm | 2 | generic | 8.0 | 16.0 | wing nacelle mounting
Printed nacelle cradle | PETG or ASA, see cad/out/ | 3 | self-printed | 0.6 | 1.8 | 6.8 cm3 each
Printed nacelle yoke | PETG or ASA, see cad/out/ | 3 | self-printed | 1.2 | 3.6 | 14.2 cm3 each
Printed fit coupon | PETG, test print before committing | 1 | self-printed | 0.7 | 0.7 | verifies M3 pattern and bearing seat
Flight controller | Pixhawk 6C or 6X, PX4 v1.17.0 | 1 | Holybro | 200.0 | 200.0 | 6 servo + 3 motor outputs required
Camera, nose | 1920x1080 @ 30 fps, 78 deg HFOV | 1 | Arducam / generic | 45.0 | 45.0 | 45 g, pitched 15 deg down; forward of every rotor disc
GPS / compass | M9N or better | 1 | Holybro | 60.0 | 60.0
Airspeed sensor | differential pitot, I2C | 1 | Holybro / Matek | 55.0 | 55.0 | NOT optional: PX4 gates transition on airspeed
Battery | 6S Li-ion, 1170 g | 1 | generic | 95.0 | 95.0 | 25% of MTOW
M3 socket cap screws | assorted 8-25 mm | 1 | generic | 9.0 | 9.0 | kit
TOTAL (indicative, excl. printing and shipping) |  |  |  |  | 756.1 | prices are estimates

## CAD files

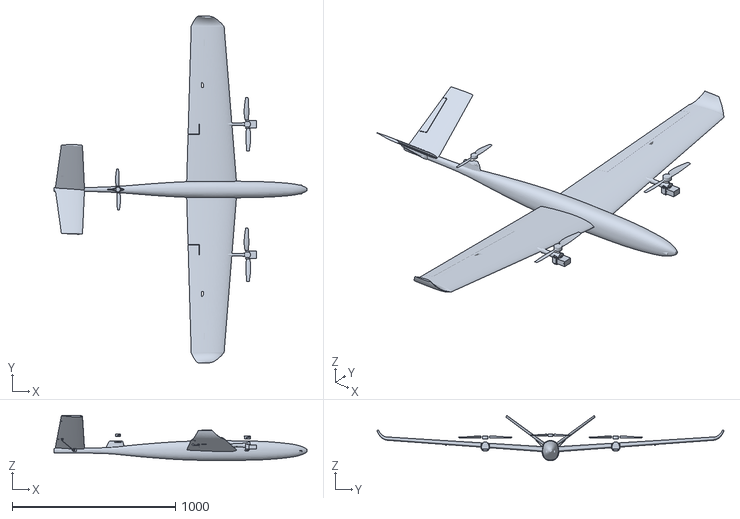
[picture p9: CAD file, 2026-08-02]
cad/out/stl/tri_tiltrotor_full.stl
1550.0 x 2126.1 x 276.3

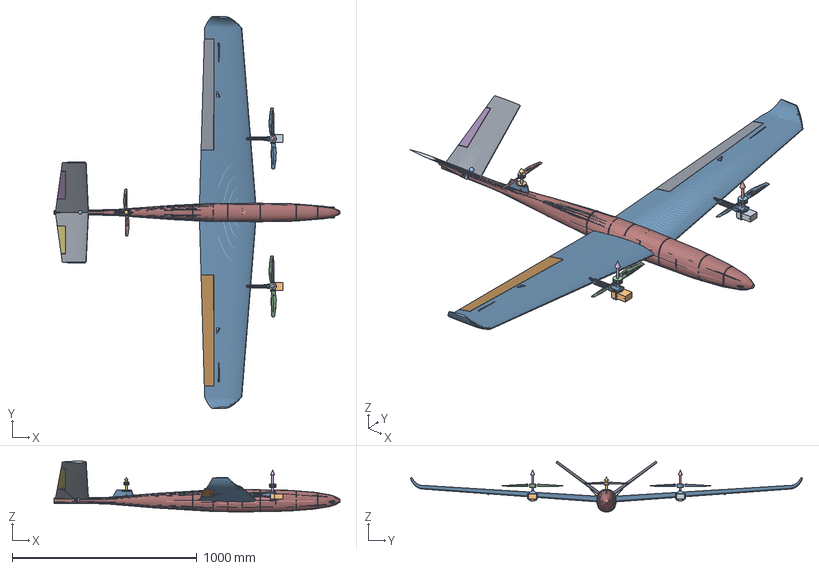
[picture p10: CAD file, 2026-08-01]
cad/originals/tri_tiltrotor.FCStd
1550.0 x 2126.1 x 275.7 mm
aileron_left
aileron_right
booms
formers
fuselage
linkages
nacelle_cradle_left_mm
nacelle_cradle_right_mm
nacelle_yoke_left_mm
nacelle_yoke_right_mm
prop_left
prop_right
prop_tail
ruddervator_left
ruddervator_right
structure
tail
tail_motor_mount_mm
wing
CG_marker
thrust_wing_L
thrust_wing_R
thrust_lift
BATTERY_marker
m_wing
m_fuselage
m_tail
m_wing001
m_tail001
m_aileron
m_tilt
m_nose
m_flight
m_esc

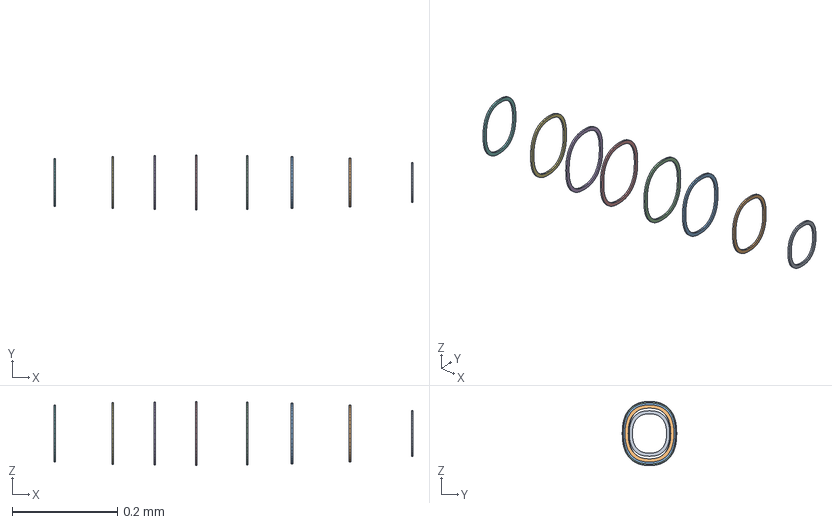
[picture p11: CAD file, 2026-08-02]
cad/out/airframe_formers.step
0.681 x 0.104 x 0.122 mm

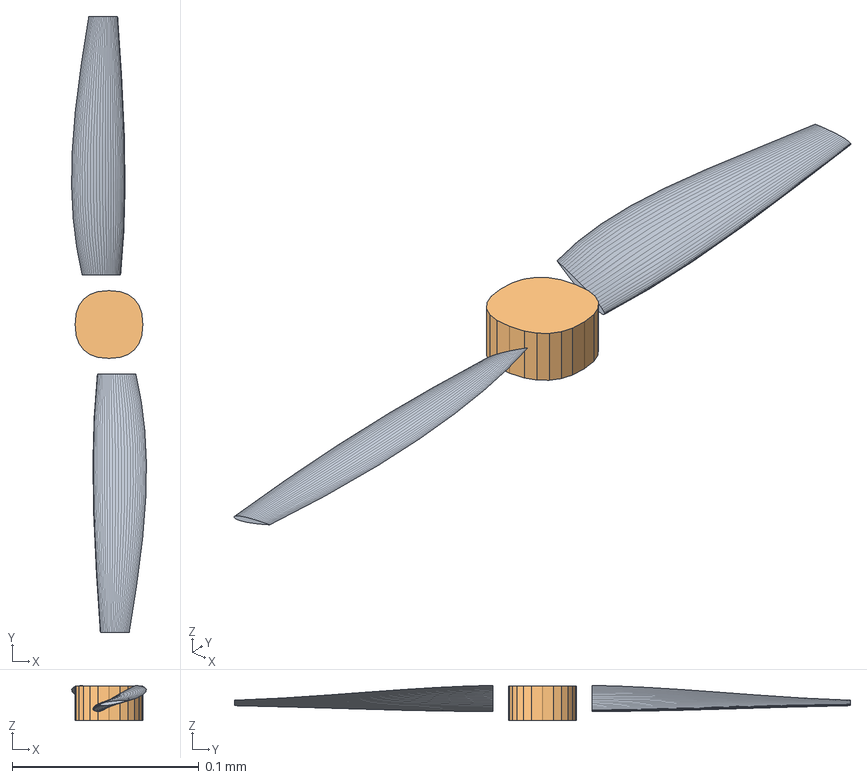
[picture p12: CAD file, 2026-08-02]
cad/out/assembly/prop_right.step
0.0401 x 0.33 x 0.0189 mm

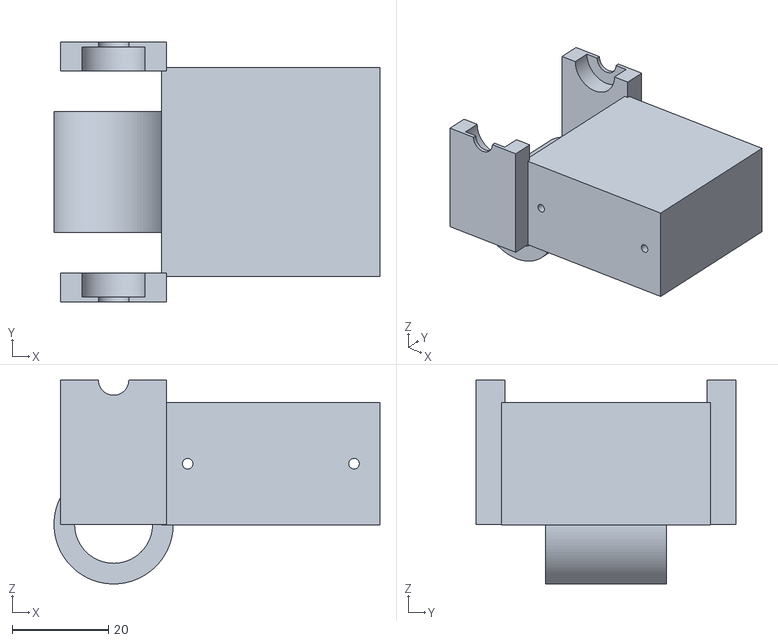
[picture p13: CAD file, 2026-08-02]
cad/out/stl/assembly/nacelle_yoke_left.stl
67.8 x 54.0 x 42.4

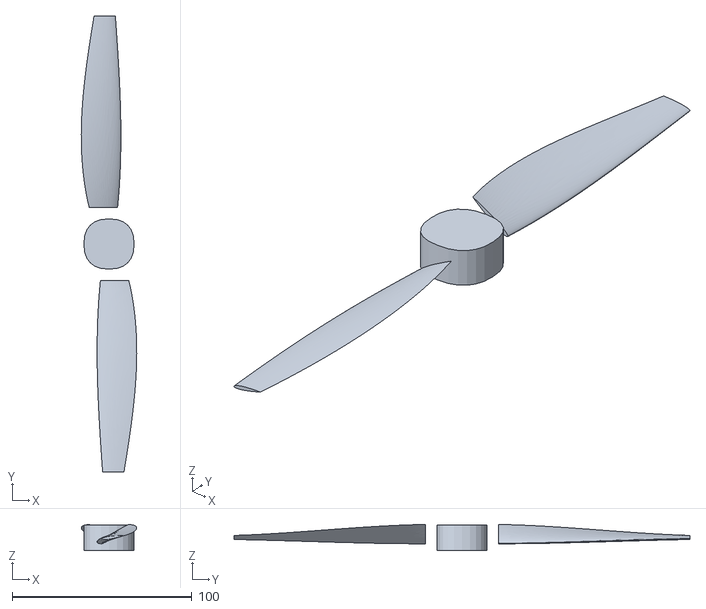
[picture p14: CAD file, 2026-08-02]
cad/out/stl/print/prop_tail.stl
30.9 x 254.0 x 14.6

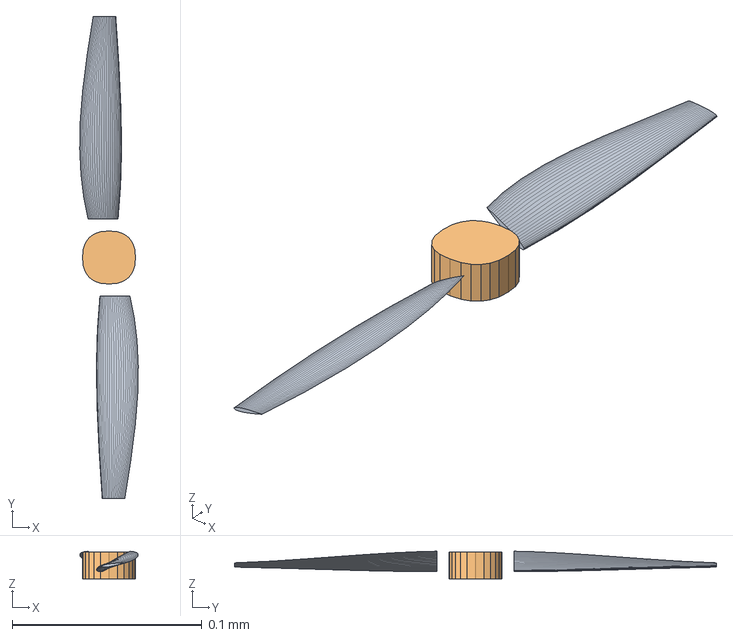
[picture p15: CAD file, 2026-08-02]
cad/out/airframe_prop_tail.step
0.0309 x 0.254 x 0.0146 mm

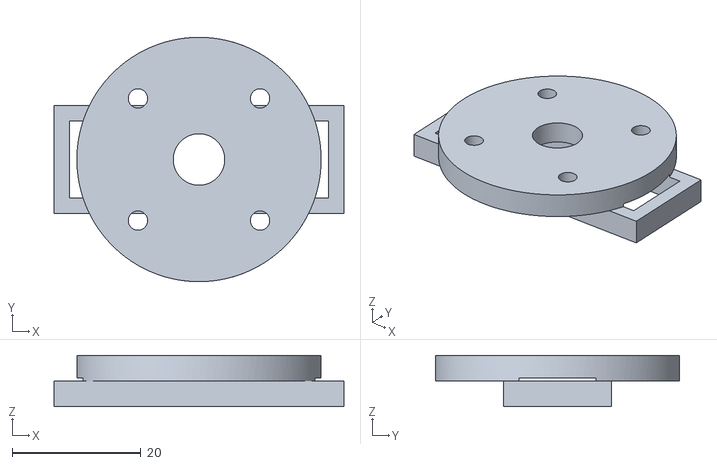
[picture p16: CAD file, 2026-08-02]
cad/out/stl/assembly/tail_motor_mount.stl
45.1 x 38.0 x 8.00

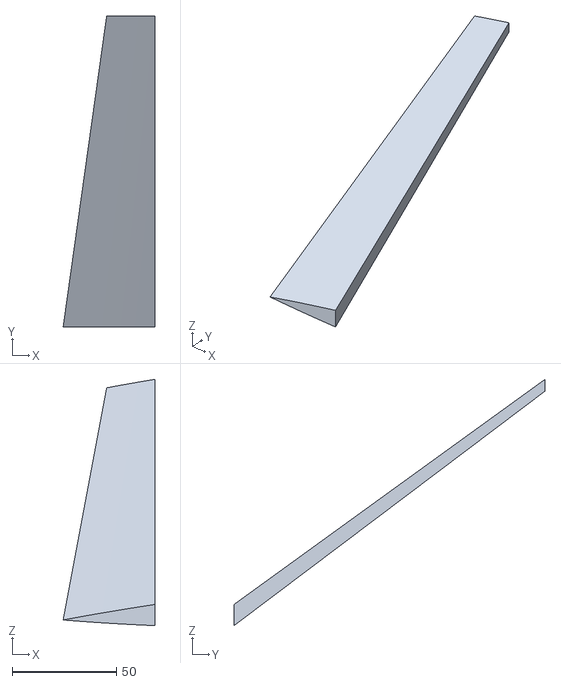
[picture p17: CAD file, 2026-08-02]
cad/out/stl/print/ruddervator_left.stl
43.9 x 148.9 x 117.9

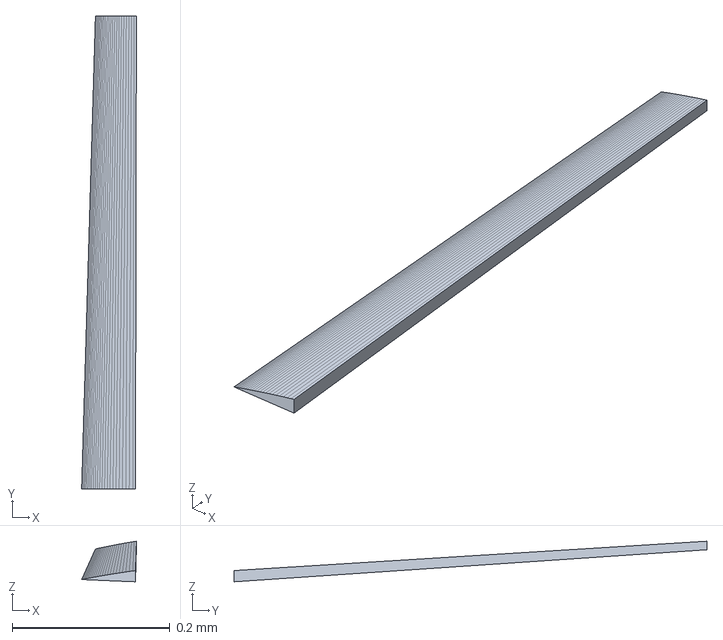
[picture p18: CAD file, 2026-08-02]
cad/out/airframe_aileron_left.step
0.0695 x 0.6 x 0.0515 mm

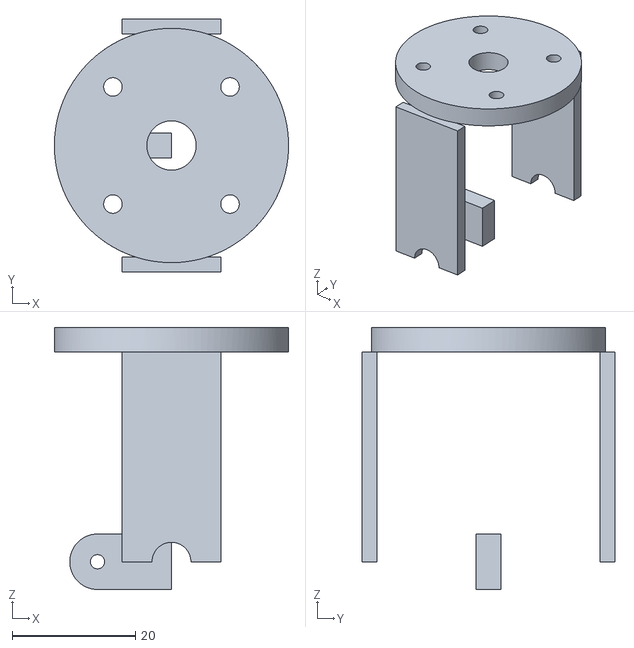
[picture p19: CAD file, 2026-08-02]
cad/out/stl/assembly/nacelle_cradle_left.stl
38.0 x 41.0 x 42.5

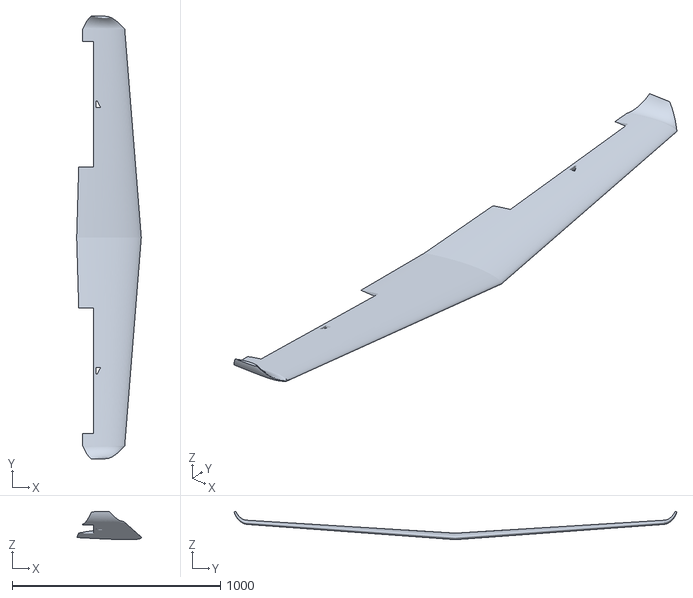
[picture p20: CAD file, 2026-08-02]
cad/out/stl/print/wing.stl
310.5 x 2126.1 x 136.3

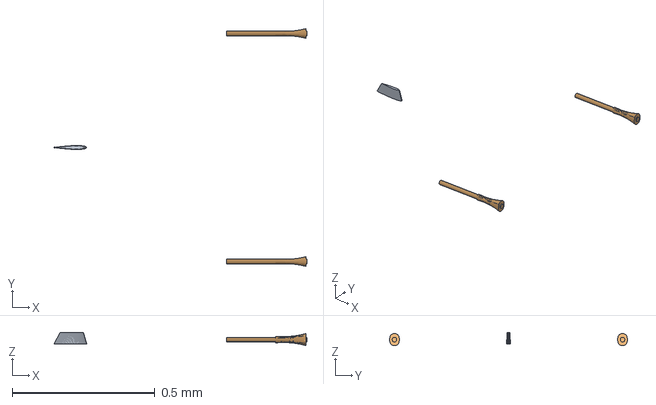
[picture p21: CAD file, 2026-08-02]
cad/out/airframe_booms.step
0.888 x 0.834 x 0.0461 mm

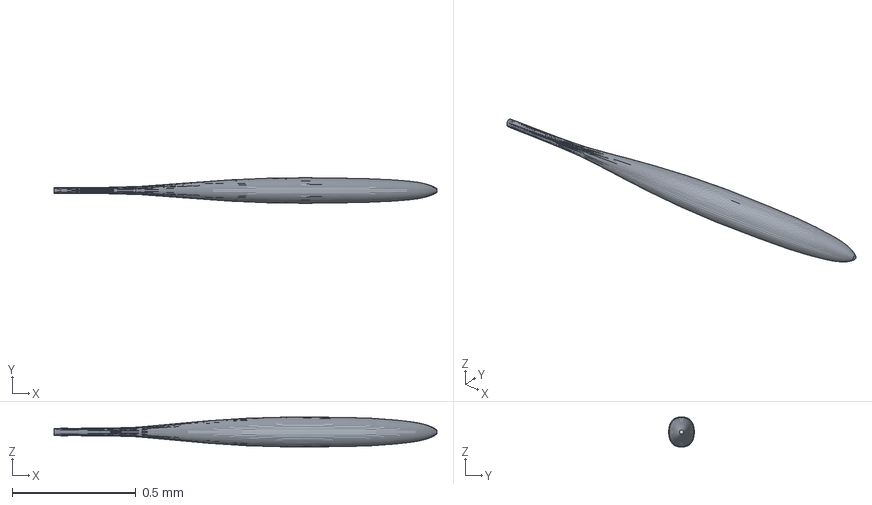
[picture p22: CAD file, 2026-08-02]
cad/out/assembly/fuselage.step
1.55 x 0.104 x 0.121 mm

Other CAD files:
tools/tri_tiltrotor-original-v2.FCStd
cad/out/assembly/nacelle_yoke_right_mm.step
tools/tri_tiltrotor -2.FCStd
cad/out/assembly/nacelle_yoke_left_mm.step
cad/out/airframe_aileron_right.step
cad/out/airframe_fuselage.step
cad/out/airframe_linkages.step
cad/out/airframe_prop_wing.step
cad/out/airframe_ruddervator_left.step
cad/out/airframe_ruddervator_right.step
cad/out/airframe_structure.step
cad/out/airframe_tail.step
cad/out/airframe_wing.step
cad/out/assembly/aileron_left.step
cad/out/assembly/aileron_right.step
cad/out/assembly/booms.step
cad/out/assembly/formers.step
cad/out/assembly/linkages.step
cad/out/assembly/nacelle_cradle_left_mm.step
cad/out/assembly/nacelle_cradle_right_mm.step
cad/out/assembly/prop_left.step
cad/out/assembly/prop_tail.step
cad/out/assembly/ruddervator_left.step
cad/out/assembly/ruddervator_right.step
cad/out/assembly/structure.step
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

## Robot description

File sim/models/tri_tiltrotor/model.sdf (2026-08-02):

<?xml version="1.0" ?>
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
<sdf version="1.9">
  <model name="tri_tiltrotor">
    <pose>0 0 0.180000 0 0 0</pose>

    <link name="base_link">
      <inertial>
        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
        <pose>-0.014469 0 0 0 0 0</pose>
        <mass>3.840000</mass>
        <inertia>
          <ixx>0.366667</ixx>
          <iyy>0.273682</iyy>
          <izz>0.640348</izz>
          <ixy>0</ixy><ixz>0</ixz><iyz>0</iyz>
        </inertia>
      </inertial>

      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

      <sensor name="imu_sensor" type="imu">
        <always_on>1</always_on>
        <update_rate>250</update_rate>
        <imu>
          <angular_velocity>
            <x><noise type="gaussian"><mean>0</mean><stddev>0.00034</stddev></noise></x>
            <y><noise type="gaussian"><mean>0</mean><stddev>0.00034</stddev></noise></y>
            <z><noise type="gaussian"><mean>0</mean><stddev>0.00034</stddev></noise></z>
          </angular_velocity>
          <linear_acceleration>
            <x><noise type="gaussian"><mean>0</mean><stddev>0.004</stddev></noise></x>
            <y><noise type="gaussian"><mean>0</mean><stddev>0.004</stddev></noise></y>
            <z><noise type="gaussian"><mean>0</mean><stddev>0.004</stddev></noise></z>
          </linear_acceleration>
        </imu>
      </sensor>
      <sensor name="air_pressure_sensor" type="air_pressure">
        <always_on>1</always_on>
        <update_rate>50</update_rate>
        <air_pressure>
          <pressure><noise type="gaussian"><mean>0</mean><stddev>0.01</stddev></noise></pressure>
        </air_pressure>
      </sensor>
      <sensor name="magnetometer_sensor" type="magnetometer">
        <always_on>1</always_on>
        <update_rate>100</update_rate>
        <magnetometer>
          <x><noise type="gaussian"><mean>0.000000080</mean><stddev>0.0001</stddev></noise></x>
          <y><noise type="gaussian"><mean>0.000000040</mean><stddev>0.0001</stddev></noise></y>
          <z><noise type="gaussian"><mean>0.000000120</mean><stddev>0.0001</stddev></noise></z>
        </magnetometer>
      </sensor>
      <sensor name="navsat_sensor" type="navsat">
        <always_on>1</always_on>
        <update_rate>30</update_rate>
      </sensor>
    </link>

    <link name="airspeed_link">
      <pose relative_to="base_link">0 0 0 0 0 0</pose>
      <inertial>
        <mass>0.015</mass>
        <inertia>
          <ixx>1e-05</ixx><iyy>1e-05</iyy><izz>1e-05</izz>
          <ixy>0</ixy><ixz>0</ixz><iyz>0</iyz>
        </inertia>
      </inertial>
      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
      <sensor name="air_speed" type="air_speed">
        <gz_frame_id>airspeed_link</gz_frame_id>
        <pose>0 0 0 0 0 0</pose>
        <update_rate>5.0</update_rate>
        <always_on>1</always_on>
        <visualize>false</visualize>
      </sensor>
    </link>
    <joint name="airspeed_joint" type="fixed">
      <parent>base_link</parent>
      <child>airspeed_link</child>
    </joint>
    <link name="chase_cam_link">
      <pose relative_to="base_link">-2.20 0 0.75 0 0.15 0</pose>
      <inertial>
        <mass>0.001</mass>
        <inertia><ixx>1e-07</ixx><iyy>1e-07</iyy><izz>1e-07</izz>
          <ixy>0</ixy><ixz>0</ixz><iyz>0</iyz></inertia>
      </inertial>
      <sensor name="chase_cam" type="camera">
        <always_on>1</always_on>
        <update_rate>30</update_rate>
        <camera>
          <horizontal_fov>1.05</horizontal_fov>
          <image><width>1920</width><height>1080</height><format>R8G8B8</format></image>
          <clip><near>0.05</near><far>2000</far></clip>
        </camera>
      </sensor>
    </link>
    <joint name="chase_cam_joint" type="fixed">
      <parent>base_link</parent>
      <child>chase_cam_link</child>
    </joint>

    <link name="nacelle_cam_link">
      <pose relative_to="base_link">0.900000 0.850000 0.150000 0 0.122171 -2.587456</pose>
      <inertial>
        <mass>0.001</mass>
        <inertia><ixx>1e-07</ixx><iyy>1e-07</iyy><izz>1e-07</izz>
          <ixy>0</ixy><ixz>0</ixz><iyz>0</iyz></inertia>
      </inertial>
      <sensor name="nacelle_cam" type="camera">
        <always_on>1</always_on>
        <update_rate>30</update_rate>
        <camera>
          <horizontal_fov>0.95</horizontal_fov>
          <image><width>1080</width><height>1920</height><format>R8G8B8</format></image>
          <clip><near>0.02</near><far>500</far></clip>
        </camera>
      </sensor>
    </link>
    <joint name="nacelle_cam_joint" type="fixed">
      <parent>base_link</parent>
      <child>nacelle_cam_link</child>
    </joint>
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

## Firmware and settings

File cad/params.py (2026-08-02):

r"""
Single source of truth for the tri-tiltrotor VTOL.

Every dimension, mass and aerodynamic coefficient in this project lives HERE and
nowhere else. The Gazebo SDF, the PX4 airframe file, the URDF and the printed
nacelle CAD are all *generated* from this module, so the simulated aircraft and
the printed part cannot drift apart.

This is the same structure that worked on 01-nav2-deck. `check()` runs the design
invariants in plain arithmetic BEFORE any CAD kernel or simulator starts, and
refuses to emit an aircraft that cannot hover, cannot trim, or whose props
intersect. A geometry error should fail here in 30 ms, not after a 90 s build.

Axes (PX4/ROS FRD body frame, right-handed):
    +x forward (nose)     +y right (starboard)     +z down

Longitudinal stations are quoted as distances FROM THE CG, positive forward.

Run directly to print the design report:
    .\.venv-cad\Scripts\python.exe projects\04-tiltrotor-vtol\cad\params.py
"""

from __future__ import annotations

import math
from dataclasses import dataclass, field

# ---------------------------------------------------------------------------
# Physical constants
# ---------------------------------------------------------------------------

G = 9.80665          # m/s^2
RHO = 1.2041         # kg/m^3, ISA sea level 20 C -- matches PX4's stock SDF


# ---------------------------------------------------------------------------
# Design inputs.  These are the only numbers a human should edit.
# ---------------------------------------------------------------------------

# --- Mass -------------------------------------------------------------------
# Every item is listed separately. Folding the battery into "fuselage" is how
# a mass budget silently stops closing -- check() enforces that these sum to
# MTOW, and it caught exactly that error on the first run of this file.
# ⚠ 4.80 -> 4.64 kg, reconciled against mass_ledger(). The drop is almost
# entirely the tail nacelle losing its tilt hardware (0.25 -> 0.10 kg). MTOW is
# no longer a number typed at the top and defended by adjusting others to match:
# the "declared MTOW matches the mass ledger" invariant now checks it against
# the itemised list.
MASS_TOTAL = 4.64            # kg, MTOW
MASS_WING_PANEL = 0.55       # kg, each of two wing panels
MASS_FUSELAGE = 0.85         # kg, fuselage structure only
MASS_AVIONICS = 0.35         # kg, FC + GPS + ESCs + wiring
MASS_BATTERY = 1.17          # kg, 6S 8000 mAh Li-ion
MASS_PAYLOAD = 0.16          # kg, camera + 2D lidar
MASS_TAIL_ASSY = 0.22        # kg, tail surfaces + boom
MASS_NACELLE_WING = 0.35     # kg, each wing nacelle (motor + tilt servo + mount)
# ⚠ 0.25 -> 0.10 kg. This was sized when the tail nacelle TILTED: it carried a
# yoke, a cradle, two 686ZZ bearings, a 6 mm shaft and a 20 kg.cm servo. All of
# that is gone -- the rotor is fixed and the mount is now a 5.1 cm^3 plate.
# What is left is the motor (~55 g), the printed mount (~6 g) and prop plus
# wiring (~35 g).
#
# This matters far beyond 150 g of MTOW: it sits 620 mm behind the CG, so the
# stale figure was contributing 93 g.m of phantom aft moment and dragging the
# whole CG solution aft with it.
MASS_NACELLE_TAIL = 0.10     # kg, fixed tail motor + mount + prop

# Mass carried at or very near the CG. Used for the pitch-inertia estimate.
MASS_CENTRAL = MASS_FUSELAGE + MASS_AVIONICS + MASS_BATTERY + MASS_PAYLOAD

# --- Wing -------------------------------------------------------------------
WING_SPAN = 2.00             # m, tip to tip
WING_CHORD = 0.26            # m, MEAN aerodynamic chord
WING_TAPER = 0.65            # tip chord / root chord
WING_DIHEDRAL = math.radians(4.0)
WING_TWIST_TIP = math.radians(-2.0)   # washout: tip stalls after the root
WING_LE_SWEEP = math.radians(3.0)

# --- Winglets ---------------------------------------------------------------
# A winglet recovers some induced drag by making the tip vortex do less work,
# which is worth more on a high-aspect-ratio wing like this one than on a
# stubby one. Height is quoted as a fraction of SEMI-span.
#
# The drag benefit below is an ESTIMATE from the standard span-efficiency
# correction, not a computed result. It is the one aerodynamic number in this
# file that is not derived, and it is flagged as such in the report.
WINGLET_HEIGHT_FRAC = 0.085      # of semi-span
WINGLET_CANT = math.radians(72.0)  # from horizontal; 90 = vertical
WINGLET_TAPER = 0.42             # tip chord / winglet root chord
WINGLET_SWEEP = math.radians(28.0)
WINGLET_TOE = math.radians(-1.5)   # slight toe-out, standard practice

# --- Tail rotor configuration -----------------------------------------------
# True  : the tail nacelle tilts 0-90 deg and becomes a pusher in cruise.
#         This is the configuration PX4 does not ship, and the reason this
#         project exists.
# False : the tail rotor is fixed vertical, stops in cruise, and is dead
#         weight plus drag -- the conventional arrangement.
#
# Priced: a stopped, unfeathered 10 in prop presents roughly 0.004 m^2 of flat
# plate. At cruise that is about 1.0 N against a 3.5 N cruise requirement, so
# roughly 30% more cruise drag. Folding props recover most of it, at the cost
# of another mechanism.
TAIL_TILTS = False

# Airfoil, NACA 4-digit. 2412 is a conventional cambered section: 2% camber at
# 40% chord, 12% thick. Chosen because its 2-D characteristics are published
# and standard, so the coefficients below are traceable rather than invented.
# 2410, not 2412: 10% thick rather than 12%. At this Reynolds number and wing
# loading the extra 2% buys structural depth we do not need and costs profile
# drag and frontal area. It also simply looks like an aircraft rather than a
# glider trainer.
WING_NACA = "2410"
TAIL_NACA = "0009"           # symmetric, as tail sections must be, and thin

# Section 2-D properties for NACA 2410 -- MEASURED, not assumed.
#
# These were hand-estimated until XFOIL was run on the section at this
# aircraft's own Reynolds numbers (aero/run_xfoil.sh, Ncrit 5). Every value
# below is now interpolated to the CONVERGED STALL Reynolds number of 199,489,
# which is itself a fixed point: CL_max sets the stall speed, the stall speed
# sets the chord Reynolds number, and that sets CL_max.
#
# Ncrit 5, not XFOIL's default 9. Ncrit 9 models a smooth, clean, low-turbulence
# surface. This wing is 3D printed.
#
# What the old estimates got wrong, and by how much:
#   CL_max      1.400 -> 1.219   the big one; 15% optimistic, and it was
#                               optimistic at exactly the low Reynolds number
#                               where stall actually happens. Stall speed rises
#                               10.74 -> 11.51 m/s and the whole envelope with it.
#   CD_min      0.0069 -> 0.00868  the old value is roughly the Re 1,000,000
#                               figure. This aircraft never goes above 393,000.
#   CL_alpha    2*pi -> 6.0215  thin-airfoil theory is the inviscid limit; a
#                               real boundary layer at Re 2e5 does not reach it.
#   alpha_stall 15.5 -> 13.18 deg
#
# Re-measure with:  bash aero/run_xfoil.sh 5
WING_CL_ALPHA_2D = 6.0215          # 1/rad, XFOIL at Re 199,489, Ncrit 5
WING_CL_MAX_2D = 1.219             # 2-D section maximum, measured
WING_CD_MIN = 0.00868              # section minimum drag, measured
WING_ALPHA_ZERO_LIFT = math.radians(-2.069)
WING_ALPHA_STALL_2D = math.radians(13.179)
OSWALD_E = 0.80

# Non-lifting parasitic drag: fuselage, nacelles, booms, gear. Expressed as an
# equivalent flat-plate area so it does not silently scale with wing area.
PARASITE_AREA = 0.0075       # m^2

# --- Fuselage shape ---------------------------------------------------------
# Stations as (x from nose / total length, half-height m, half-width m).
# Lofted through these, so it is a shaped body rather than a box.
# ⚠ 1.35 -> 1.55 m. At 1.35 the body ENDED at x = -0.872 m while the V-tail's
# root chord runs -0.825 .. -1.005 m: only the forward 47 mm of a 180 mm root
# had any fuselage under it and the remaining 133 mm cantilevered off the back
# attached to nothing. Widening the last station (the previous fix) gave the
# root something to bolt to but did not make the body reach far enough aft.
#
# The station table below is re-fractioned for the new length so the waist
# still lands under the lift rotor, and now ends as a slender constant-section
# tail boom that runs past the V-tail trailing edge instead of tapering to a
# point under its leading edge.
FUSELAGE_LENGTH = 1.55       # m, runs aft of the V-tail trailing edge
# Slimmer and more streamlined than the first pass: maximum section reduced
# from 0.072 to 0.061 m half-height, and more stations so the loft is smooth
# rather than visibly segmented. Fineness ratio (length / max diameter) goes
# from 8.2 to 10.2, which is squarely in the low-drag range for a body of
# revolution; below about 6 the pressure drag climbs sharply.
FUSELAGE_STATIONS = (
    (0.000, 0.008, 0.008),
    (0.030, 0.030, 0.027),
    (0.080, 0.044, 0.039),
    (0.160, 0.055, 0.047),
    (0.280, 0.060, 0.051),
    (0.360, 0.061, 0.052),
    (0.440, 0.059, 0.050),
    (0.520, 0.054, 0.045),
    (0.610, 0.044, 0.036),
    (0.690, 0.033, 0.026),
    # --- cut-down rear deck ---
    # The upper rear fuselage is cut away hard from here back. Two reasons:
    #   1. wetted area. This section carries no payload, no structure worth
    #      the name and no fuel -- it is pure skin friction.
    #   2. it lets the lift rotor sit LOW without burying it. The pylon drops
    #      from 75 mm to 34 mm because the deck it stands on came down to meet
    #      it, rather than the rotor coming down into the wash.
    # The result is a tail boom rather than a tapering body.
    (0.760, 0.022, 0.018),
    # From here aft it is a TAIL BOOM of near-constant section, not a taper to
    # a point. The V-tail root chord sits on 0.86 .. 1.00, so the body has to
    # still be there over all of it.
    (0.800, 0.018, 0.015),
    (0.860, 0.016, 0.013),
    (0.910, 0.015, 0.013),
    (0.960, 0.015, 0.012),
    # ⚠ CORRECTED. This station used to be (1.000, 0.005, 0.004): the body
    # tapered to a 10 x 8 mm needle exactly where the V-tail bolts on. The tail
    # root chord is 180 mm and its NACA 0009 section is 16.2 mm thick, so a
    # 0.128 m^2 tail was attached to something half as thick as itself. It
    # would have failed on the first hard landing.
    #
    # check() passed it because the only relevant invariant was "fuselage is
    # long enough to carry the tail", which compares LENGTH (1.35 m vs 0.956 m)
    # and never looks at whether there is any SECTION at the root.
    #
    # Ending the body as a small constant boom instead of a point gives the
    # root 28 x 24 mm to land on. Deliberately chosen not to disturb the waist
    # invariants: waist_half is max(h) over frac >= 0.80, which is 0.016 at the
    # 0.845 station either way, so the cut-down-deck and waisting checks are
    # unaffected.
    (1.000, 0.014, 0.012),
)

# --- Longitudinal layout ----------------------------------------------------
# CG position as a fraction of MAC, measured aft of the wing leading edge.
CG_MAC_FRACTION = 0.28       # 28% MAC
# Wing rotor plane, measured FORWARD of the wing leading edge (on booms).
WING_ROTOR_AHEAD_OF_LE = 0.100   # m
# Tail rotor plane, measured AFT of the CG.
# Moved FORWARD of the V-tail (was 0.780, behind it) to sit on a pylon at the
# fuselage waist. This is the industry-standard arrangement, and it is only
# viable because the tail rotor is hover-only: in cruise it is stopped, so it
# lays no wake over the tail surfaces -- the one condition in which tail
# effectiveness actually matters for stability.
# ⚠ 0.700 -> 0.620. At 0.700 the disc swept back to 0.827 m and the V-tail sat
# at 0.870 m -- a 43 mm gap from a 254 mm rotor. The old invariant passed it
# because it only asked "is the tail INSIDE the disc band, yes/no", and 43 mm
# is technically outside. A hover wake contracts AND spreads; 43 mm is nothing.
# The V-tail was flying in the lift rotor's downwash in hover, which is a
# nose-down disturbance exactly when attitude hold matters most.
#
# Moving the rotor forward costs a little: a shorter arm means the tail rotor
# carries MORE of the hover lift (9.32 -> 10.3 N), which the trim solve and the
# motor-headroom check both re-verify rather than my asserting it is fine.
TAIL_ROTOR_ARM = 0.620       # m
# Pylon height above the fuselage upper surface.
#
# Cut down from 75 mm. The original justification -- lift the rotor out of the
# fuselage boundary layer -- is weaker than it sounds: in HOVER there is no
# freestream, so there is no boundary layer, and in CRUISE this rotor is
# stopped. It only genuinely matters through the brief transition.
#
# The reason not to delete the pylon entirely is download, not inflow: with the
# hub sitting on the skin, the fuselage sits inside the rotor's own downwash
# and steals thrust. Measured trade:
#   pylon drag in cruise : ~0.03-0.05 N of a 3.35 N requirement  (~1.5%)
#   download if recessed : ~0.5-0.9 N of a 9.32 N lift rotor     (~5-10%)
# So a short pylon wins, but only just, and mostly in hover.
TAIL_PYLON_HEIGHT = 0.034    # m, above the fuselage upper surface
# Tail aerodynamic surfaces, measured AFT of the CG.
# Deliberately FORWARD of the tail rotor disc band. At 0.860 m the horizontal
# tail sat inside the 0.653-0.907 m disc sweep and would have flown in its own
# rotor wash in hover -- caught by check(), not by eye.
# V-tail moved right to the back, behind the rotor. The longer arm buys the
# same effectiveness from a SMALLER surface -- tail volume scales with
# area x arm, so 0.620 -> 0.870 m lets the areas drop by the same ratio.
TAIL_SURFACE_ARM = 0.870     # m

# --- V-tail -----------------------------------------------------------------
# Two surfaces instead of three: less wetted area, one fewer junction making
# interference drag, lighter, fewer parts to print. It is what essentially
# every modern fixed-wing VTOL uses, and PX4 allocates it natively
# (CA_SV_CS*_TYPE 7 = Left V-Tail, 8 = Right V-Tail).
#
# A V-tail at dihedral angle GAMMA from horizontal resolves into:
#     effective pitch area = S * cos^2(GAMMA)
#     effective yaw   area = S * sin^2(GAMMA)
# so GAMMA is chosen to reproduce the pitch/yaw split a conventional tail
# would have given, and the required total area follows. Both are DERIVED in
# solve(), not typed in, so they cannot disagree with the geometry.
# Scaled down with the longer arm (0.620 -> 0.870 m) to hold the SAME tail
# volume coefficients from ~29% less area. Less wetted surface, less weight,
# less drag -- bought purely by moving the surfaces aft.
TAIL_PITCH_AREA_REQ = 0.0784  # m^2, effective horizontal area needed
TAIL_YAW_AREA_REQ = 0.0428    # m^2, effective vertical area needed
# 0.150 m forced 0.567 m panels -- a 0.91 m projected tail span on a 2.0 m
# wing, which check() rejected. 0.18 m gives 0.47 m panels and a 0.76 m
# projected span, 38% of wing span, which is where real VTOL V-tails sit.
TAIL_CHORD = 0.180           # m

# V-tail incidence, leading edge DOWN (negative), relative to the fuselage
# waterline.
#
# WHY IT IS NOT ZERO. With the tail at 0 deg, AVL had to hold -8.67 deg of
# ruddervator to trim at cruise. That is the elevator carrying, permanently, a
# download the tail should be making by its own shape. The cost is about 1.6%
# of cruise drag (measured: CDind 0.0068252 trimmed vs 0.0063203 with the
# elevator locked at zero) and -- the part that matters more -- roughly a third
# of the ruddervator's one-sided travel is consumed before the autopilot asks
# for anything.
#
# Setting incidence is the standard fix and it is free: it changes no
# stability derivative, only the angle at which the surface floats. Solved by
# running AVL at two incidences and interpolating to zero elevator, so this
# number is measured, not chosen. Re-solve with aero/solve_tail_incidence.sh.
TAIL_INCIDENCE = math.radians(-2.49)

# --- Control surfaces -------------------------------------------------------
# These lived as bare literals inside gen_sdf.py, which meant the simulated
# hinge and any drawn geometry could disagree without anything noticing. They
# belong here with every other dimension.
#
# The surfaces used to be emitted as plain <box> visuals: grey slabs pasted
# near the trailing edge, floating clear of a wing that is tapered, swept and
# dihedralled. They are now lofted from the actual aerofoil section, hinged on
# the real hinge line. Note this is COSMETIC ONLY -- the Gazebo LiftDrag
# plugins read the joint ANGLE, never the mesh, so the aerodynamics are
# identical either way.
AILERON_SPAN_FRAC = 0.30      # of wing span
AILERON_Y_FRAC = 0.32         # spanwise centre, of wing span
AILERON_CHORD_FRAC = 0.25     # of local chord, hinged at 75% chord
RUDDERVATOR_SPAN_FRAC = 0.55  # of V-tail panel span
RUDDERVATOR_CHORD_FRAC = 0.30 # of tail chord
CONTROL_DEFLECT_MAX = math.radians(30.0)

# --- Servos and electrical load ---------------------------------------------
# SIX servos, not three. Four control surfaces (2 ailerons, 2 ruddervators) plus
# two wing tilts. The tail nacelle is fixed, so it has no tilt servo.
#
# The BOM listed three TILT servos and NO control-surface servos at all, and
# the flight controller line asked for "7 servo outputs" -- both left over from
# the tilting-tail layout. PX4 allocates SIM_GZ_SV_FUNC1..4 to the surfaces and
# 5..6 to the tilts, so the real requirement is 6 servo + 3 motor outputs.
N_SERVO_SURFACE = 4
N_SERVO_TILT = 2
# Control surfaces are far less loaded than the tilt axis: aerodynamic hinge
# moment only, no thrust vector and no nacelle weight hanging off the axis.
SURFACE_SERVO_TORQUE_KGCM = 8.0
# Peak current per servo at stall. Servos do not all stall at once in practice,
# but the 5 V rail has to survive it if they do.
SERVO_STALL_CURRENT_A = 2.5
# A Pixhawk's internal regulator cannot feed six servos. This is the single
# electrical fact that decides whether a separate BEC is needed.
FC_INTERNAL_BEC_MAX_A = 1.5

# --- Nose camera -------------------------------------------------------------
# 1080p forward-looking payload camera in the nose. Sits ahead of the avionics
# bay where it has a clear view below the wing and outside every propeller disc.
CAMERA_ENABLED = True
CAMERA_WIDTH = 1920
CAMERA_HEIGHT = 1080
CAMERA_FPS = 30
CAMERA_HFOV = math.radians(78.0)   # typical 1080p module
CAMERA_MASS = 0.045                # kg, module + lens + mount
CAMERA_TILT_DOWN = math.radians(15.0)   # looks slightly down, as survey cams do

# --- Equipment bay -----------------------------------------------------------
# Everything that has to physically fit inside the fuselage, with real module
# dimensions. `x` is the station of the item's CENTRE, in the model frame,
# positive forward of the CG.
#
# This exists so "where do the electronics go" is answered by arithmetic against
# the actual fuselage section rather than by hoping. check() verifies every item
# fits inside the lofted envelope at its station -- a fuselage that is 122 mm
# across at its widest cannot swallow a 100 mm battery at a station where the
# body has narrowed to 60 mm, and until now nothing said so.
#
# (name, x_centre_m, length_mm, width_mm, height_mm, mass_kg)
# ⚠ REARRANGED after the CG was computed rather than assumed. With the battery
# at +20 mm the CG landed 48 mm AFT of the design point -- 46.6% MAC against a
# 20-35% window -- because 1.17 kg of battery was sitting essentially on the CG
# and doing nothing to balance the tail.
#
# solve_cg() puts the battery at +138 mm, which is where it has to be for the
# CG to land where every moment arm in the trim solve assumes it does. Avionics
# moved forward of it; nothing sits between +53 and +223 mm but the pack.
EQUIPMENT = (
    ("Nose camera",      0.418,  30.0, 30.0, 30.0, CAMERA_MASS),
    ("GPS / compass",    0.360,  50.0, 50.0, 16.0, 0.032),
    ("Flight controller", 0.285,  85.0, 45.0, 20.0, 0.100),
    ("Battery 6S",       0.138, 170.0, 70.0, 55.0, MASS_BATTERY),
    ("Airspeed sensor",  0.020,  25.0, 20.0, 15.0, 0.015),
    ("ESC x3",          -0.130,  70.0, 60.0, 20.0, 0.090),
    ("BEC",             -0.210,  40.0, 25.0, 12.0, 0.025),
)

# --- Lateral layout ---------------------------------------------------------
# Wing rotor lateral station, measured from centreline.  This single number
# sets roll authority in hover -- see check_roll_authority().
WING_ROTOR_Y = 0.400         # m
FUSELAGE_HALF_WIDTH = 0.060  # m

# --- Rotors -----------------------------------------------------------------
WING_PROP_DIAMETER = 0.3302  # m, 13 in
# FOLDING prop. Not a detail: a stopped, unfeathered 10 in disc presents about
# 0.004 m^2 of flat plate, worth ~1.0 N against a 3.3 N cruise requirement --
# roughly 30% more cruise drag, straight off the endurance. A folding prop
# streamlines against the pylon and recovers nearly all of it. This is why
# every production aircraft in this layout uses one.
TAIL_PROP_DIAMETER = 0.2540  # m, 10 in, FOLDING
TAIL_PROP_FOLDING = True
# Peak static thrust each motor can produce, from the motor/prop datasheet.
WING_MOTOR_THRUST_MAX = 38.0  # N
TAIL_MOTOR_THRUST_MAX = 25.0  # N
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

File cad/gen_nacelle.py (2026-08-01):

r"""
Tilt nacelle mechanism -- the printed part -- generated from params.py.

Three printed pieces, all driven by the same params.py that produces the
Gazebo model and the PX4 airframe:

  nacelle_cradle  holds the motor and rotates on the tilt shaft
  nacelle_yoke    clamps to the wing boom and carries the bearings
  fit_coupon      bolt pattern + one bearing seat + one shaft bore, a few
                  grams, so a buyer can verify the fits before committing
                  filament to the real part

The coupon is not decoration. Same constraint that governed 02: there is no
physical aircraft here, so nothing can be test-fitted, and the honest answer
is to ship the tolerances as a printable test rather than assert them.

Design rules forced by having no hardware to check against:
  - clearance fits only, never press fits
  - every mating dimension carries an explicit budgeted clearance
  - the listing must say "tolerances verified in CAD only"

Run:
    .\.venv-cad\Scripts\python.exe projects\04-tiltrotor-vtol\cad\gen_nacelle.py
"""

from __future__ import annotations

from pathlib import Path

from build123d import (
    Align, Axis, BuildPart, BuildSketch, Circle, Cylinder, GridLocations,
    Location, Locations, Mode, Plane, Rectangle, RotationLike, Box,
    export_step, export_stl, extrude, fillet, import_step,
)

import params as P

OUT = Path(__file__).resolve().parent.parent / "cad" / "out"

# Derived mechanism dimensions -------------------------------------------------
YOKE_INNER_W = P.NACELLE_WIDTH_MM                 # inside face to inside face
CRADLE_OUTER_W = YOKE_INNER_W - 1.0               # 0.5 mm clearance per side
BEARING_SEAT_D = P.BEARING_OD_MM + P.BEARING_SEAT_CLEARANCE_MM
SHAFT_BORE_D = P.TILT_SHAFT_DIA_MM + P.SHAFT_BORE_CLEARANCE_MM
BOOM_BORE_D = P.BOOM_DIA_MM + P.BOOM_CLAMP_CLEARANCE_MM

CRADLE_ARM_H = 34.0        # from the underside of the motor plate to the axis
YOKE_ARM_H = 30.0          # from the boom centreline up to the axis
CRADLE_ARM_W = 16.0        # arm width fore/aft


def build_cradle():
    """Motor plate plus two depending arms carrying the tilt shaft."""
    half = CRADLE_OUTER_W / 2.0

    with BuildPart() as cradle:
        # --- motor mount plate ---
        Cylinder(
            radius=P.CRADLE_PLATE_DIA_MM / 2.0,
            height=P.CRADLE_PLATE_MM,
            align=(Align.CENTER, Align.CENTER, Align.MAX),
        )

        # --- the two arms ---
        with Locations((0, 0, -CRADLE_ARM_H / 2.0 - P.CRADLE_PLATE_MM)):
            with GridLocations(
                x_spacing=0, y_spacing=CRADLE_OUTER_W - P.WALL_MM,
                x_count=1, y_count=2,
            ):
                Box(CRADLE_ARM_W, P.WALL_MM, CRADLE_ARM_H)

        # --- tilt shaft bore through both arms ---
        axis_z = -(P.CRADLE_PLATE_MM + CRADLE_ARM_H)
        with Locations(Location((0, 0, axis_z), (90, 0, 0))):
            Cylinder(
                radius=SHAFT_BORE_D / 2.0,
                height=CRADLE_OUTER_W + 4.0,
                mode=Mode.SUBTRACT,
            )

        # --- motor bolt pattern, M3 on a square pitch ---
        with BuildSketch(Plane.XY.offset(0.0)):
            with GridLocations(
                x_spacing=P.MOTOR_BOLT_PITCH_MM,
                y_spacing=P.MOTOR_BOLT_PITCH_MM,
                x_count=2, y_count=2,
            ):
                Circle(radius=P.MOTOR_BOLT_DIA_MM / 2.0)
        extrude(amount=-P.CRADLE_PLATE_MM, mode=Mode.SUBTRACT)

        # --- central bore for shaft and wiring ---
        with BuildSketch(Plane.XY):
            Circle(radius=P.MOTOR_SHAFT_CLEAR_MM / 2.0)
        extrude(amount=-P.CRADLE_PLATE_MM, mode=Mode.SUBTRACT)

        # --- DRIVEN HORN ------------------------------------------------------
        # ⚠ This is what was missing. The cradle rotated on a shaft in bearings
        # with nothing connected to it: the servo existed in the BOM and in the
        # torque calculation, and nowhere in the geometry. Without a horn there
        # is no way to convert servo rotation into nacelle tilt, so the
        # "mechanism" was a bearing assembly, not an actuator.
        #
        # The arm projects AFT of the tilt axis by SERVO_HORN_RADIUS_MM. The
        # servo horn on the yoke has the same radius, so the linkage is 1:1 and
        # the servo's travel maps directly onto the nacelle's -15..+90 deg.
        r = P.SERVO_HORN_RADIUS_MM
        with Locations(Location((0, 0, axis_z))):
            # Arm: a flat lug from the shaft boss out to the pushrod hole.
            with Locations((-r / 2.0, 0, 0)):
                Box(r, P.HORN_ARM_THICK_MM, P.HORN_BOSS_DIA_MM)
            # Boss around the pushrod hole, so the ball link has material.
            with Locations(Location((-r, 0, 0), (90, 0, 0))):
                Cylinder(radius=P.HORN_BOSS_DIA_MM / 2.0,
                         height=P.HORN_ARM_THICK_MM)

        # Pushrod hole through the horn.
        with Locations(Location((-r, 0, axis_z), (90, 0, 0))):
            Cylinder(radius=P.PUSHROD_HOLE_DIA_MM / 2.0,
                     height=P.HORN_ARM_THICK_MM + 4.0, mode=Mode.SUBTRACT)

    return cradle.part
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

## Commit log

2026-08-01 changes and fixes to frame, installed front wing mounts for the flap servo control along with rear wings still in working
    [BOM.csv, aileron_left.step, aileron_right.step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]
2026-08-01 final design adjustments for now
    [BOM.csv, aileron_left.step, aileron_right.step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]
2026-08-02 tiltrotor CFD, polar drags and other coefficients tested in sim
    [aileron_left.step, aileron_right.step, airframe_aileron_left.step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]
2026-08-02 AVL, XFLR5 analysis in
    [airframe_aileron_left.step, airframe_aileron_right.step, airframe_booms.step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]
2026-08-02 minor adjustments
    [aileron_left.step, aileron_left.stl, aileron_right.step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]
